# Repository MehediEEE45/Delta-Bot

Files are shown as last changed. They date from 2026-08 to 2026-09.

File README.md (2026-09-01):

# Delta-Bot

A small desk robot built on an ESP32-C3. It shows a face on a 128×64 OLED,
reacts when you tap it, drives around from a web page on your phone, and keeps
a to-do list and a Pomodoro timer that you can see without picking up anything.

I built it because I wanted something on my desk that felt like it was *there* —
not another blinking status LED. Most of the work went into the face.

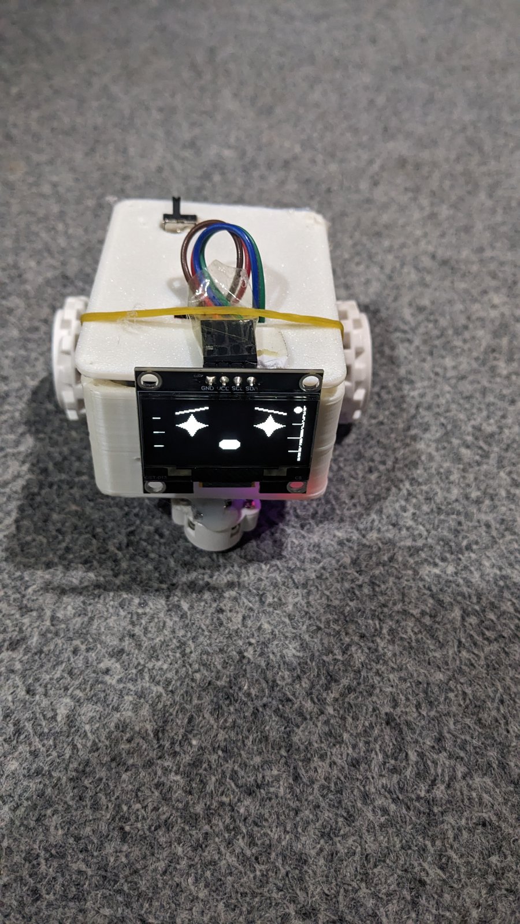
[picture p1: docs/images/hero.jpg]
Delta-Bot, face on






---

## What it does

| | |
| :--- | :--- |
| **Animated face** | The screen it boots to. Nine expressions on the OLED, each with its own eye shape, brow angle and mouth. Blinks at random intervals, drifts slightly when idle, and glances around on its own. Left alone it eases into a new expression every 15-30 seconds. |
| **Touch** | One capacitive pad, and the only control you need. A tap steps to the next screen, a triple tap steps back, a double tap throws a random expression on the face, and holding it puts the bot to sleep. |
| **RC driving** | A D-pad on the web page drives the two motors. The eyes lean into the turn. Motors cut out after one second if the browser stops sending, so a dropped connection can't run it off the desk. |
| **Voice** | The web page uses the browser's own speech recognition — say "forward", "left", "happy". No cloud service, no API key. Needs a secure page (see below); heard text is echoed to both the web page and the OLED. |
| **Clock and weather** | NTP time on a decorative ring that sweeps once a minute, timezone and 12h/24h format set from the web page and applied instantly. Current conditions from Open-Meteo, location also set from the web page, with drawn icons for sun, cloud, fog, rain, snow and storms. |
| **To-do list** | Up to five tasks, added from the web page, ticked off from either end. Survives a reboot. |
| **Pomodoro** | Focus length is set from the web page (1-180 minutes, default 25), with a fixed 5-minute break; a ring sweeps around the display as the interval burns down. Pauses and resumes properly. |
| **Virtual pet** | The pet screen shows a full animated face — happy when cared for, sad or angry if left hungry — plus a brief eating animation right after you feed it. Feed it from the web page, or double-tap the pad on the pet screen to pat it. |
| **Pixel canvas** | A 16×16 grid on your phone draws straight onto the OLED. |
| **Desk guard** | Arm it, and anyone who touches the bot gets a flashing alarm face and a wheel twitch. |
| **Night mode** | Switches to a moon-and-stars screen after 22:00 and puts your mode back at 06:00. |

On power-up it paints a name card - a Δ mark that rises, then **DELTA** assembling
under it - which also proves the panel and the I²C wiring before Wi-Fi is even
attempted, then settles on the animated face.

The pad walks a fixed ring of eight screens: **face, clock, weather, tasks,
pomodoro, pet, quotes, music**. The event-driven screens (notice, reminder, desk
guard, decision, night, RC) are left out of the ring on purpose, since landing on
one by accident would only show you a stale or empty panel; those still appear
when the web page or a trigger pushes them.

Everything is served from the bot itself. There's no app and nothing phones home;
the only outbound request is the weather fetch.

---

## Hardware

### Parts list

| Part | Qty | Notes |
| :--- | :---: | :--- |
| ESP32-C3 SuperMini | 1 | Any ESP32-C3 board works. Build targets `esp32-c3-devkitm-1`, which is the standard stand-in — PlatformIO has no SuperMini definition. |
| 128×64 OLED, I²C | 1 | SSD1306 or SSD1305, 0.96". Get the one with the header on the **long** edge if you're printing the lid. |
| TB6612FNG motor driver | 1 | **Not a DRV8833.** See the warning below. |
| N20 gear motors, 6 V | 2 | 100–200 RPM is about right. Faster than that and it skitters. |
| TTP223 touch module | 1 | The cheap 3-pin one. |
| LiPo 3.7 V, ~1000 mAh | 1 | Plus a TP4056 charger board — get the variant **with** DW01 protection. |
| Wheels, 34 mm | 2 | For a 3 mm D-shaft. |

> ### The motor driver is not interchangeable
>
> The firmware drives **one PWM pin plus two direction pins per channel**
> (`PWMA` / `AIN1` / `AIN2`, plus `STBY`). That's the TB6612FNG interface.
>
> A **DRV8833 will not work with this wiring.** It has no `PWMA`/`PWMB` pins at
> all — you PWM the direction pins directly — and its enable is `nSLEEP`, not
> `STBY`. Wire a DRV8833 to this pinout and the motors will only ever run flat
> out. If a DRV8833 is what you have, tie `GPIO 1` to `nSLEEP` and rework
> `MotorController::setMotor()` to PWM the direction pins instead.

### Pinout

| Signal | GPIO | Goes to |
| :--- | :---: | :--- |
| I²C SDA | 8 | OLED SDA |
| I²C SCL | 9 | OLED SCL |
| Touch | 4 | TTP223 SIG |
| Left PWM | 3 | TB6612 PWMA |
| Left dir 1 | 5 | TB6612 AIN1 |
| Left dir 2 | 6 | TB6612 AIN2 |
| Right PWM | 0 | TB6612 PWMB |
| Right dir 1 | 7 | TB6612 BIN1 |
| Right dir 2 | 10 | TB6612 BIN2 |
| Standby | 1 | TB6612 STBY |

All of these live in [`include/Config.h`](include/Config.h) — the C3's GPIO
matrix means you can move any of them without touching another file.

### Wiring

```text
                     ┌──────────────────┐
     USB 5V ────────▶│  TP4056 + DW01   │
                     │   charge board   │
                     └───┬──────────┬───┘
                    BAT+ │          │ OUT+
                  ┌──────┴────┐     │
                  │ LiPo 3.7V │     │  3.2 - 4.2 V rail
                  └───────────┘     │
                                    ├──────────────────┐
                                    ▼                  ▼
                        ┌───────────────────┐   ┌─────────────┐
                        │  TB6612FNG   VM   │   │  ESP32-C3   │
                        │              VCC ◀├───┤ 3V3     5V  │
                        │              GND  │   │             │
                        │                   │   │             │
                        │  PWMA ◀───────────┼───┤ GPIO 3      │
                        │  AIN1 ◀───────────┼───┤ GPIO 5      │
                        │  AIN2 ◀───────────┼───┤ GPIO 6      │
                        │  PWMB ◀───────────┼───┤ GPIO 0      │
                        │  BIN1 ◀───────────┼───┤ GPIO 7      │
                        │  BIN2 ◀───────────┼───┤ GPIO 10     │
                        │  STBY ◀───────────┼───┤ GPIO 1      │
                        │                   │   │             │
                        │  AO1 AO2 BO1 BO2  │   │ GPIO 8 ─────┼──▶ OLED SDA
                        └───┬───┬───┬───┬───┘   │ GPIO 9 ─────┼──▶ OLED SCL
                            │   │   │   │       │             │
                          ┌─┴───┴─┐┌┴───┴─┐     │ GPIO 4 ◀────┼─── TTP223 SIG
                          │ N20 L ││ N20 R│     └─────────────┘
                          └───────┘└──────┘
                                              OLED + TTP223 VCC ── 3V3
                                              everything GND ───── common
```

```mermaid
graph LR
    BAT["LiPo 3.7V<br/>+ TP4056"] -->|VM, motor rail| DRV["TB6612FNG"]
    BAT -->|regulated| MCU["ESP32-C3"]
    MCU -->|3V3 logic| DRV
    MCU -->|"I2C · GPIO 8/9"| OLED["128x64 OLED"]
    TOUCH["TTP223"] -->|"GPIO 4"| MCU
    DRV --> ML["Left N20"]
    DRV --> MR["Right N20"]
    MCU -.->|"Wi-Fi · web UI"| PHONE["Your phone"]
```

### Three things that will bite you

**Power the motors from the battery, not the 3V3 pin.** `VM` on the TB6612 goes
to the LiPo rail; `VCC` is the logic supply and goes to 3V3. Every ground must be
common. Two N20s stalling will pull well over an amp, which no dev-board
regulator will survive.

**Feeding the ESP32 is the part worth thinking about.** A 3.7 V cell is below
what most 5 V pins want and above what's safe to inject straight into 3V3 at full
charge (4.2 V). A small boost converter to 5 V is the boring, correct answer.
Going LiPo-direct into 3V3 works right up until it doesn't.

**GPIO 8 and 9 are strapping pins.** That's the Arduino I²C default and normally
fine, but on a SuperMini board GPIO 8 usually also drives the onboard LED and
GPIO 9 is the BOOT button. If the bot sometimes refuses to start, this is the
first place to look: check for pull-ups on SDA/SCL and keep the leads short.

---

## Photos

| | |
| :--- | :--- |
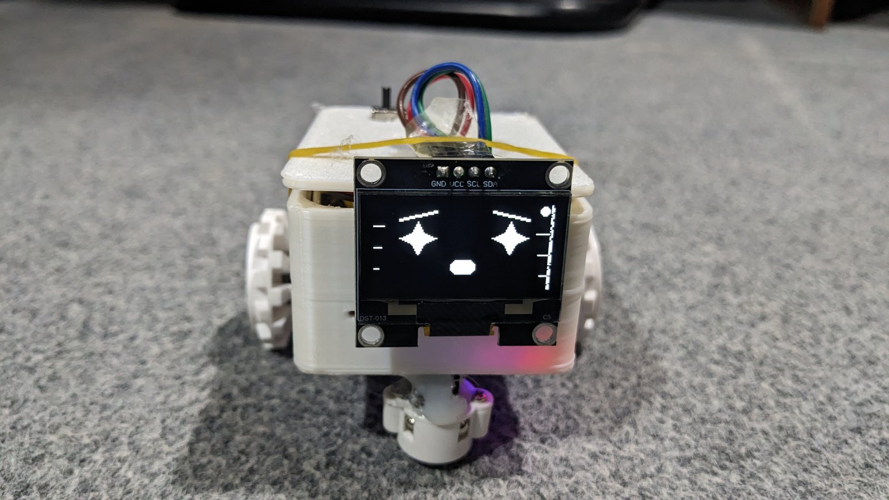
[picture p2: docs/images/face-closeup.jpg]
Face close-up
|  | **The face.** OLED filling the frame, shot slightly off-axis so the glass doesn't blow out. This is the project. |
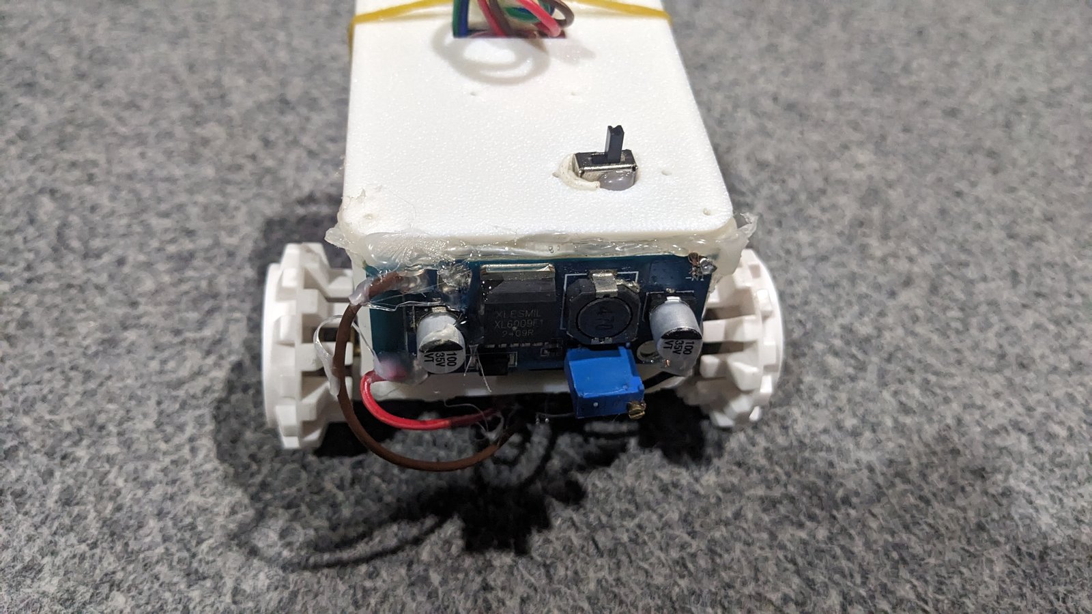
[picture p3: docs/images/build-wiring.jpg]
Bench wiring
|  | **The tail end.** Boost converter, power switch and the wiring that feeds the ESP32 — the single most useful photo in any hardware repo, since people copy wiring from photos, not diagrams. |
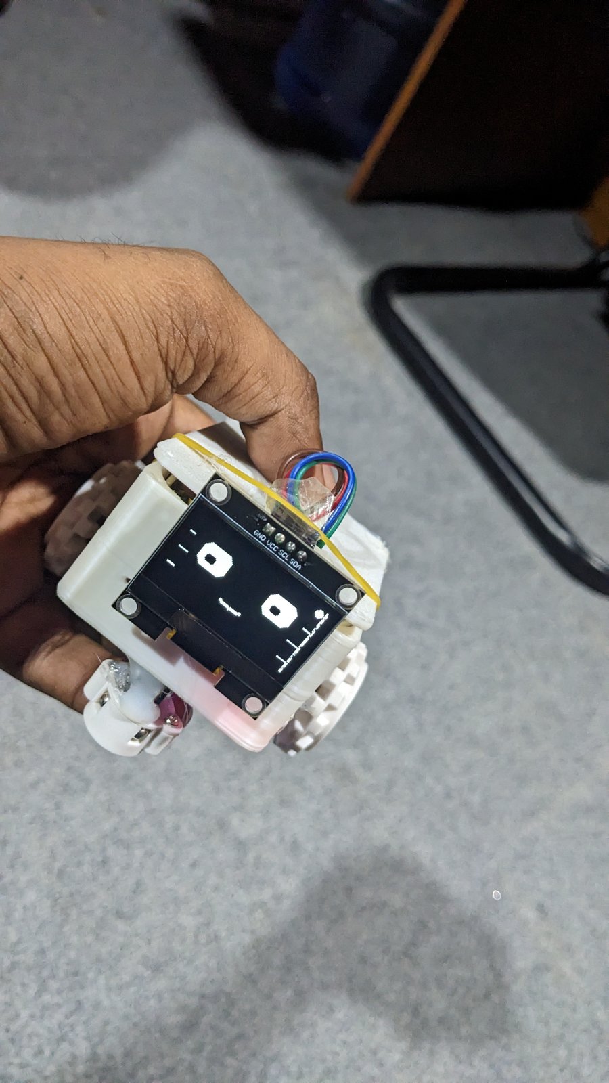
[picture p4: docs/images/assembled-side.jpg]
Held in hand, for scale
|  | **Actual size.** It's small — a hand around it answers "how big is it" faster than a ruler would. |

A phone screenshot of the web dashboard is still on the shot list — drop one
into `docs/images/web-ui.png` and add `![Web dashboard](docs/images/web-ui.png)`
here once it exists.

There's also a short clip of it driving around. GitHub won't play an `.mp4`
referenced by a repo-relative path inline, so once it's uploaded somewhere
(YouTube, etc.), add a link here:

<!-- **[Watch it drive](PASTE_VIDEO_URL_HERE)** -->

---

## Printed parts

Four parts in [`hardware/3d_models/`](hardware/3d_models): body, lid, a motor
bracket (print two), and a clamp that holds the touch sensor against the lid.
PLA, 0.2 mm, 20% infill, supports only on the body.

Print settings, tolerances and the assembly order are in
[`hardware/3d_models/README.md`](hardware/3d_models/README.md). The short version:
mount the motors before anything else goes in, or you won't reach the screws.

---

## Getting it running

You'll need [VS Code](https://code.visualstudio.com/) and the
[PlatformIO extension](https://platformio.org/platformio-ide).

```bash
git clone https://github.com/MehediEEE45/Delta-Bot.git
cd Delta-Bot
cp include/Secrets.h.example include/Secrets.h
```

Then fill in `include/Secrets.h`. It's gitignored, so nothing here gets committed:

```cpp
namespace Config {
constexpr char WIFI_SSID[]     = "YOUR_WIFI_SSID";
constexpr char WIFI_PASSWORD[] = "YOUR_WIFI_PASSWORD";

// Password for the fallback access point the bot starts when it can't
// join your network. Needs 8+ characters or it falls back to an open AP.
constexpr char FALLBACK_AP_PASSWORD[] = "CHANGE_ME_AP";

// Login for the web dashboard. Every endpoint that changes something is
// behind this. Leave the password empty to turn auth off — but then anyone
// on your network can drive the motors and rewrite your Wi-Fi settings.
constexpr char WEB_USER[]     = "delta";
constexpr char WEB_PASSWORD[] = "CHANGE_ME_WEB";
}
```

Plug the board in, hit Upload, then open the serial monitor at 115200 to find
the IP address. Open that in a browser and you're in.

If it can't reach your network it starts its own, called **Delta**. Join that and
go to `192.168.4.1` to set the real credentials.

---

## The console

The same command set is reachable three ways — over USB serial, over Bluetooth,
and from the web page's buttons. They all run through one parser, so a command
means the same thing wherever you type it.

**Over serial:** open the monitor at 115200 and type. `help` lists everything.

**Over Bluetooth:** the bot advertises as **DELTA** over BLE, exposing a Nordic
UART service. Any generic BLE terminal works — *Serial Bluetooth Terminal* in
BLE mode, or nRF Connect. There's no app to install.

> The ESP32-C3 has no classic Bluetooth, only BLE. A classic SPP pairing — the
> kind most "Bluetooth serial" tutorials describe — cannot work on this chip.

```
status              current mode, radio, battery, uptime
wifidiag (or wifi)  re-run the radio check and report
<mode>              face, clock, weather, tasks, pomodoro, pet, quotes, music...
<emotion>           happy, love, angry, cool, excited, sad, surprised, sleep, idle
drive <dir> [speed] forward | backward | left | right | stop, 0-255
restart (or reboot) reboot the board
help (or ?)         the list
```

### When Wi-Fi doesn't come up

`wifidiag` exists to answer one question: *is the radio broken, or is it
something ordinary?* It runs a live check and separates the cases:

| Reported | What it means |
| :--- | :--- |
| `radio-dead` | The MAC came back all-zero or all-`FF`. The PHY never started — this is the hardware. |
| `scan-empty` | Radio reports a real MAC but sees zero networks. Usually the antenna, not the chip. |
| `ssid-not-found` | Radio is fine, other networks are visible, yours isn't. Out of range or hidden. |
| `auth-failed` | Your network was seen and refused the association. Check the password. |
| `timeout` | Seen, but never answered. Weak signal or a busy AP. |

The check also runs at boot. If it fails, the reason goes on the OLED for a few
seconds before the setup card appears, so you can diagnose it without a laptop
attached. The same result is on the web dashboard under **Wi-Fi Diagnostics**.

---

## The web dashboard

Served straight off the board — one page, no build step, no dependencies.

- Drive pad with a speed slider
- Every emotion and mode as a button
- Task list with add, tick and delete
- Pomodoro (with a configurable focus length), reminders, notices, the 8-ball, the pet
- Pixel canvas that draws on the OLED as you tap
- Wi-Fi setup
- Clock & Region: timezone, 12h/24h format, and weather location — all applied
  immediately, no reboot
- Voice command, echoed to both the page and the OLED

Status polls every two seconds. If a request fails, the page tells you what
happened instead of silently doing nothing.

**Voice needs a secure page.** Browsers only allow microphone access on HTTPS
or `localhost` — a device on your LAN serving plain HTTP is blocked by the
browser before the bot ever sees a request. Standing up real HTTPS on a C3
just for this isn't worth it, so the practical fix is a browser flag: open
`chrome://flags/#unsafely-treat-insecure-origin-as-secure`, add
`http://<the-bot's-ip>`, enable it, and relaunch. That's a one-time setup per
browser/device, not a bot-side limitation you'll hit again.

---

## How the code is laid out

```
src/
  main.cpp           Wi-Fi bring-up, the loop
  AppController      Mode and emotion state machine
  FaceAnimator       Expression morphing, blinking, gaze — no display calls
  FaceRenderer       Everything that draws to the OLED
  TaskManager        Tasks, pet, pomodoro, reminders, canvas
  MotorController    TB6612 driver, watchdog, non-blocking wiggle
  CommandProcessor   One command parser, shared by every control surface
  SerialConsole      Line reader on USB serial
  BleConsole         Same console over a BLE UART service
  WiFiDiagnostics    Radio check that separates hardware from config faults
  WebController      HTTP server and the dashboard page
  Weather            Open-Meteo fetch, on its own FreeRTOS task
```

Four decisions worth explaining.

**The weather fetch runs on its own task.** A TLS handshake on a C3 takes a few
seconds, and doing that inside `loop()` froze the display and the web server
solid. The C3 is single-core, so the worker and the main loop take turns rather
than running in parallel, but the face keeps animating through it.

**`FaceAnimator` never touches the display.** It works out where everything
should be and hands over a struct; `FaceRenderer` draws it. That split means the
animation maths can be tested on a laptop with fake timestamps, and it keeps the
drawing code from accumulating state.

**One command parser, three front ends.** `CommandProcessor::execute()` writes
its output to an Arduino `Print&` rather than to `Serial` directly. That one
choice is what lets serial, BLE and the web API share a single parser — each
passes its own sink, and none of them can drift into meaning something different.

**BLE callbacks don't touch app state.** NimBLE runs its write callback on the
BLE stack's own task. Mutating `AppController` from there would race the main
loop, so the callback only posts the line to a queue and `loop()` drains it —
every command still executes from exactly one thread.

There's a preview script at [`tools/preview_face.py`](tools/preview_face.py) that
renders the expressions as ASCII, so you can check the geometry without flashing
anything. It caught three real layout bugs before they ever hit hardware.

---

## Rough edges

Things I know about, listed here rather than discovered by you:

- Tasks are capped at five. It's a fixed array.
- No OTA, so updates mean plugging in a cable. The build now uses the `huge_app`
  partition layout to fit the BLE stack, and that layout has no second OTA slot —
  so this is a deliberate trade rather than a space problem now.
- The battery gauge is wired in software but there's no divider on the board, so
  the API honestly reports `batteryMeasured: false` instead of inventing a number.
- No tests and no CI. Next on the list — the touch gesture logic and the Pomodoro
  maths are both pure functions and should be tested on a laptop.
- The face was tuned against an ASCII preview, not a real panel. Some of the
  geometry will want nudging once I've stared at it for a week.

---

## License

MIT. Do what you like with it.

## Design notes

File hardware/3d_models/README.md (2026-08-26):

# Printed parts

Four parts, all printable on a stock FDM machine with no exotic settings. I
print them in PLA; PETG is worth it for the body if the bot lives somewhere warm,
since a car dashboard will soften PLA.

## The parts

| File | What it is | Size (mm) | Triangles |
| :--- | :--- | :--- | ---: |
| `body.stl` | Main shell. Holds the battery, both motors, the driver board and the ESP32. | 54 × 72 × 32 | 3,616 |
| `lid.stl` | Top plate. The OLED sits in the window, touch pad underneath. | 54 × 72 × 2 | 1,792 |
| `n20_bracket.stl` | Motor mount. Print two. | 17.3 × 26.5 × 11.5 | 1,204 |
| `sensor_clamp.stl` | Retainer that holds the TTP223 board flat against the lid. | 20 × 10 × 3.4 | 828 |

Wheels aren't here. I used off-the-shelf 34 mm rubber wheels that push onto the
N20 D-shaft, which cost about a dollar a pair and grip far better than anything
I printed. If you want to print your own, the shaft is a 3 mm D with a 0.5 mm flat.

## Print settings

Nothing here is fussy. What I use:

- **Layer height** 0.2 mm. Drop to 0.16 mm if you want a cleaner OLED bezel.
- **Walls** 3 perimeters. The motor bracket takes real load, so don't go below this.
- **Infill** 20% gyroid.
- **Supports** only on `body.stl`, touching build plate. The other three print flat.
- **PLA** 205 °C nozzle, 60 °C bed.

The lid is 2 mm thick and prints in about fifteen minutes. Print a spare — it's
the part you'll re-cut if you move the display.

## Assembly order

Order matters here, because the body gets crowded fast.

1. Press the N20 motors into the two brackets, then screw the brackets into the
   floor of `body.stl`. Do this first: once the battery is in, you can't reach
   the screws.
2. Route the motor leads up the inside wall before anything else goes in.
3. Drop in the LiPo, then the TB6612 board, then the ESP32 last — it's the one
   you'll be unplugging most often.
4. Seat the OLED in the lid window from underneath. It's a friction fit; if it's
   loose, a strip of tape on the long edge takes up the slack.
5. Put the TTP223 face-down on the lid's inner boss and hold it with
   `sensor_clamp.stl`. It reads capacitively through 2 mm of PLA — it does not
   need a hole.
6. Push the wheels onto the D-shafts.

## Fit notes

These are the tolerances I printed against. If your printer runs tight, scale
the body 100.5% rather than reprinting everything.

- Motor bracket bore is sized for a standard 12 mm N20 barrel.
- The OLED window assumes the common 27 × 27 mm 4-pin I²C module. The 0.96"
  boards with the pin header on the long edge fit; the ones with it on the short
  edge do not.
- There's no strain relief on the USB port. Be gentle with it, or add a dab of
  hot glue once you've finished flashing.

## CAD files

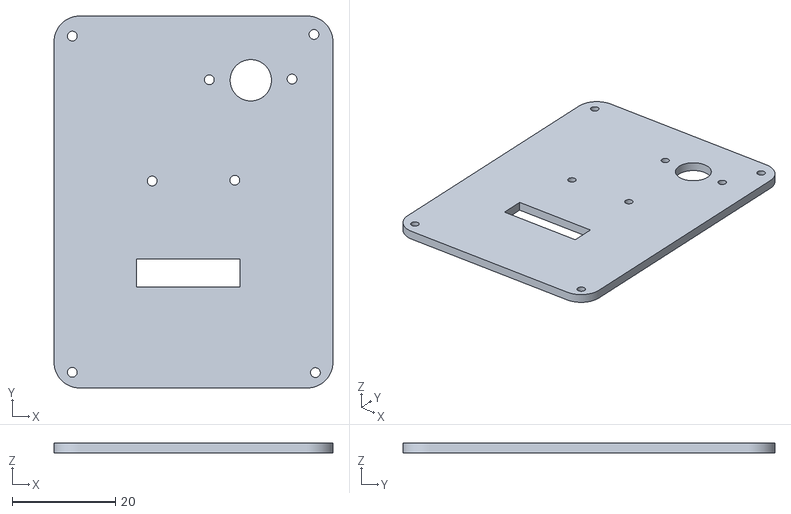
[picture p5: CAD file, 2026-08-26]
3d design/lid.stl
54.0 x 72.0 x 2.00

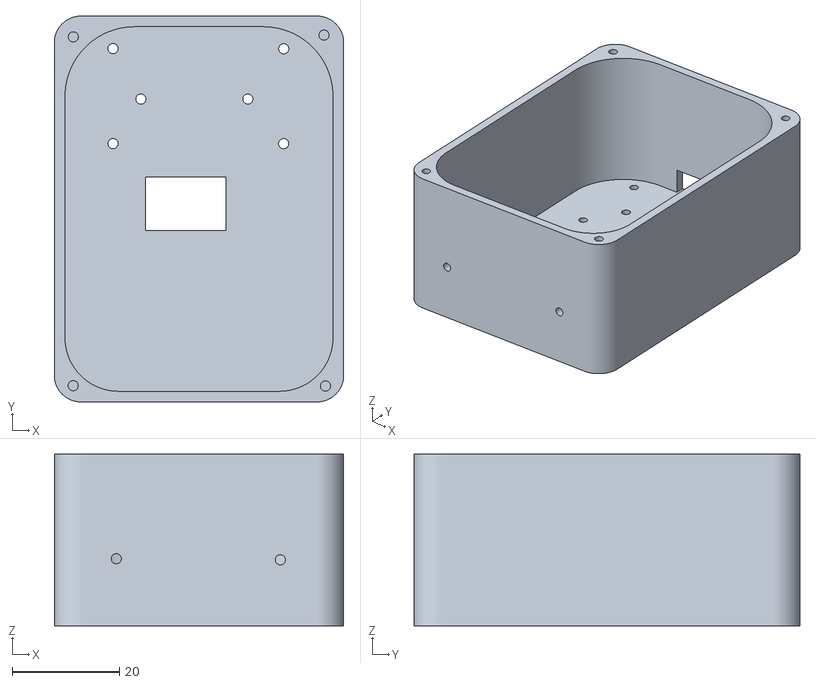
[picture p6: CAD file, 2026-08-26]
3d design/body.stl
54.0 x 72.0 x 32.0

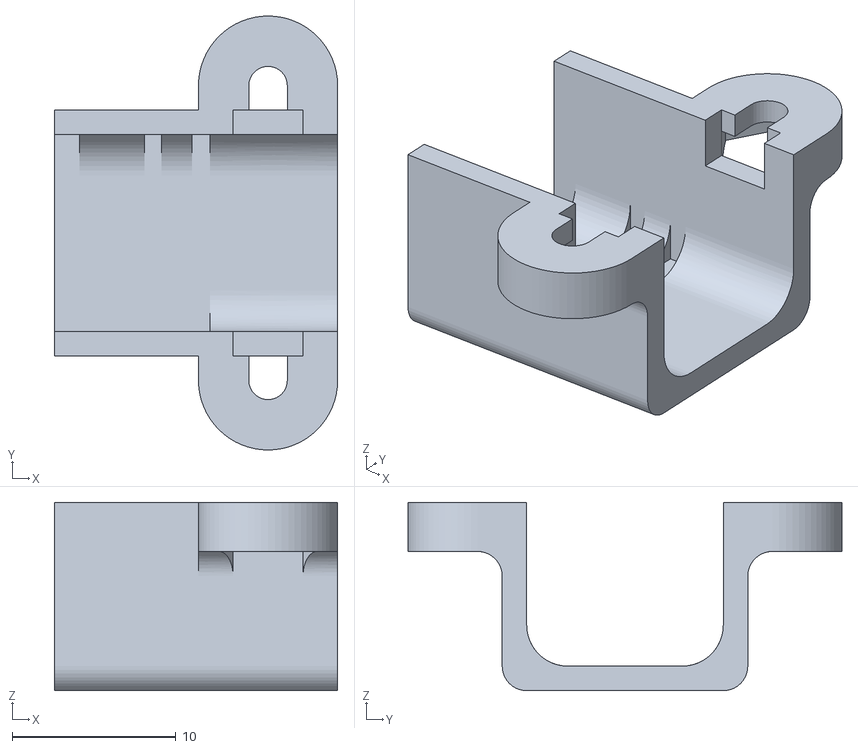
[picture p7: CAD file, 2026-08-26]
3d design/n20_bracket.stl
17.3 x 26.5 x 11.5

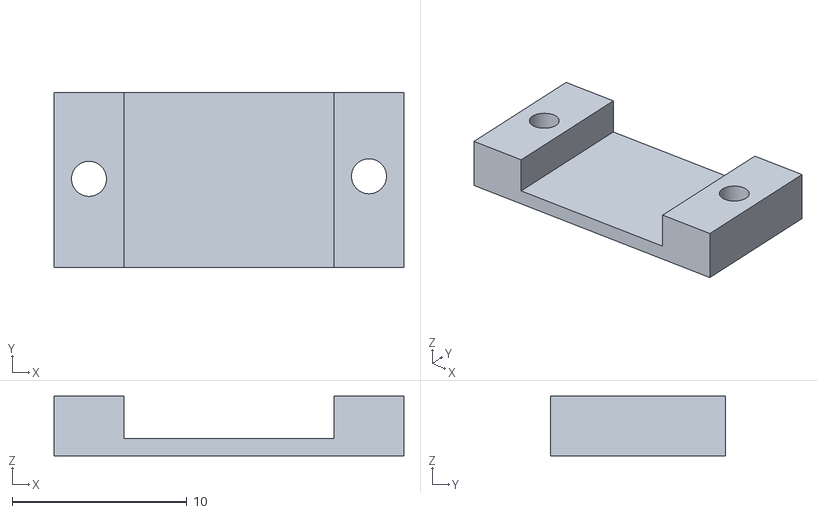
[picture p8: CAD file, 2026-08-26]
3d design/sensor_clamp.stl
20.0 x 10.00 x 3.40

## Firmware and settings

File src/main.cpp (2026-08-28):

#include <Arduino.h>
#include <WiFi.h>
#include "AppController.h"
#include "BleConsole.h"
#include "CommandProcessor.h"
#include "Config.h"
#include "FaceRenderer.h"
#include "SerialConsole.h"
#include "TouchSensor.h"
#include "WebController.h"
#include "Weather.h"
#include "WiFiDiagnostics.h"
#include "MotorController.h"

FaceRenderer renderer;
WeatherService weather;
TouchSensor touch(Config::TOUCH_PIN);
AppController app(renderer, weather);
MotorController motors(Config::MOTOR_LEFT_PWM, Config::MOTOR_LEFT_IN1, Config::MOTOR_LEFT_IN2, Config::MOTOR_RIGHT_PWM, Config::MOTOR_RIGHT_IN1, Config::MOTOR_RIGHT_IN2, Config::MOTOR_STBY);
CommandProcessor commands(app, motors);
WebController web(app, motors, commands);
SerialConsole serialConsole(commands);
BleConsole bleConsole(commands);

// What the OLED should tell the user once the radio has settled. Filled in by
// the bring-up path so the panel can repeat what used to be serial-only.
struct NetworkInfo {
  bool valid = false;
  bool apMode = false;
  String ssid;
  String password; // AP mode only; empty means the AP came up open
  String ip;
};

bool startFallbackAccessPoint(NetworkInfo& info) {
  WiFi.disconnect(true, true);
  delay(100);
  WiFi.mode(WIFI_AP);
  IPAddress apIp(192, 168, 4, 1);
  IPAddress apGateway(192, 168, 4, 1);
  IPAddress apSubnet(255, 255, 255, 0);
  WiFi.softAPConfig(apIp, apGateway, apSubnet);

  info.apMode = true;
  info.ssid = Config::FALLBACK_AP_SSID;

  if (WiFi.softAP(Config::FALLBACK_AP_SSID, Config::FALLBACK_AP_PASSWORD)) {
    Serial.print("Fallback website: http://");
    Serial.println(WiFi.softAPIP());
    Serial.print("Connect to Wi-Fi network: ");
    Serial.println(Config::FALLBACK_AP_SSID);
    Serial.println("Fallback password: (see include/Secrets.h)");
    info.valid = true;
    info.password = Config::FALLBACK_AP_PASSWORD;
    info.ip = WiFi.softAPIP().toString();
    web.begin();
    return true;
  }

  Serial.println("Secured fallback AP failed; retrying as open network.");
  if (WiFi.softAP(Config::FALLBACK_AP_SSID)) {
    Serial.print("Open fallback website: http://");
    Serial.println(WiFi.softAPIP());
    Serial.print("Connect to open Wi-Fi network: ");
    Serial.println(Config::FALLBACK_AP_SSID);
    info.valid = true;
    info.password = "";
    info.ip = WiFi.softAPIP().toString();
    web.begin();
    return true;
  }

  Serial.println("Fallback network failed to start.");
  return false;
}

// runWiFiDiagnostics() takes a plain function pointer, so the display it needs
// to keep alive is reached through the file-scope renderer rather than a
// capture.
void paintBootProgress(const char* headline, const char* detail) {
  renderer.showBootStatus(headline, detail, millis());
}

void connectWiFi(NetworkInfo& info) {
  String ssid = app.wifiSsid();
  String password = app.wifiPassword();
  ssid.trim();
  password.trim();

  if (ssid.isEmpty() || ssid == "YOUR_WIFI_SSID") {
    Serial.println("Wi-Fi not configured; starting fallback network.");
    renderer.showBootStatus("no wi-fi set", "starting setup ap", millis());
    startFallbackAccessPoint(info);
    return;
  }

  WiFi.setAutoReconnect(true);
  WiFi.disconnect(true, true);
  delay(150);

  const WiFiDiagnostics diag = runWiFiDiagnostics(ssid, password, 20000, paintBootProgress);
  commands.setLastDiagnostics(diag);
  Serial.println();
  diag.report(Serial);

  if (diag.fault == WiFiFault::None) {
    configTzTime(app.timezone(), "pool.ntp.org", "time.nist.gov");
    Serial.print("Delta web server: http://");
    Serial.println(WiFi.localIP());
    info.valid = true;
    info.apMode = false;
    info.ssid = ssid;
    info.ip = WiFi.localIP().toString();
    web.begin();
    return;
  }

  // Hold the reason on the panel before the setup card replaces it, so a
  // failure is readable without a laptop attached.
  if (renderer.ready()) {
    renderer.showWiFiDiagScreen(diag);
    delay(Config::WIFI_DIAG_CARD_MS);
  }
  Serial.println("Wi-Fi connection failed; starting Delta fallback network.");
  startFallbackAccessPoint(info);
}

// Plays the boot name card through to its settled frame. setup() has nothing
// else to do while it runs, so this blocks rather than threading splash state
// through loop().
void playSplash() {
  const unsigned long startedAt = millis();
  for (;;) {
    const unsigned long elapsed = millis() - startedAt;
    renderer.showSplash(elapsed);
    if (elapsed >= Config::SPLASH_HOLD_MS) return;
    delay(Config::SPLASH_FRAME_MS);
  }
}

// Leaves the SSID, password and address on screen long enough to be typed into
// a phone. The web server is already listening by this point, so keep pumping
// it instead of blocking on a bare delay.
void holdNetworkCard(const NetworkInfo& info) {
  if (!info.valid || !renderer.ready()) return;
  renderer.showNetworkCard(info.apMode, info.ssid, info.password, info.ip);
  const unsigned long startedAt = millis();
  while (millis() - startedAt < Config::NETWORK_CARD_MS) {
    web.update();
    delay(10);
  }
}

void setup() {
  Serial.begin(115200);
  delay(500);
  Serial.println("Delta booting");
  if (!renderer.begin()) {
    Serial.println("Continuing headless; the web UI still works.");
  } else {
    // Name card first, so a bare panel proves itself before Wi-Fi is tried.
    playSplash();
  }
  touch.begin();
  weather.begin();
  motors.begin();
  app.begin();
  NetworkInfo network;
  connectWiFi(network);
  holdNetworkCard(network);
  // BLE comes up after Wi-Fi so the radio is not being shared during the
  // association attempt the diagnostics depend on.
  bleConsole.begin();
  serialConsole.begin();
}

void loop() {
  web.update();
  const unsigned long now = millis();
  serialConsole.update();
  bleConsole.update();
  const TouchEvent touchEvent = touch.update(now);
  app.handleTouch(touchEvent, now);
  // Desk Guard warning pulse: a caught intruder gets a wheel wiggle. main owns
  // both objects, so the alarm stays decoupled from the motor driver.
  if (app.taskManager().consumeGuardAlarmPulse()) {
    motors.startShake(now);
  }
  web.update();
  motors.update(now);
  app.update(now);
}

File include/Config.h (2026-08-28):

#pragma once

#include <Arduino.h>
#include "Secrets.h"

namespace Config {
// 400kHz costs ~23ms for a full 1KB frame, which caps the face near 20fps.
// Most SSD130x modules run happily at 1000000; raise this and re-test if the
// animation looks choppy. Depends on your pull-ups and lead length.
constexpr uint32_t I2C_CLOCK_HZ = 400000;

constexpr uint8_t I2C_SDA_PIN = 8;
constexpr uint8_t I2C_SCL_PIN = 9;
constexpr uint8_t TOUCH_PIN = 4;
constexpr uint8_t MOTOR_LEFT_PWM = 3;
constexpr uint8_t MOTOR_LEFT_IN1 = 5;
constexpr uint8_t MOTOR_LEFT_IN2 = 6;
constexpr uint8_t MOTOR_RIGHT_PWM = 0;
constexpr uint8_t MOTOR_RIGHT_IN1 = 7;
constexpr uint8_t MOTOR_RIGHT_IN2 = 10;
constexpr uint8_t MOTOR_STBY = 1;
constexpr bool TOUCH_ACTIVE_HIGH = true;
constexpr uint8_t OLED_ADDRESS = 0x3C;
constexpr uint8_t BATTERY_ADC_PIN = 255;
constexpr float BATTERY_DIVIDER_RATIO = 2.0f;
constexpr float BATTERY_EMPTY_VOLTAGE = 3.30f;
constexpr float BATTERY_FULL_VOLTAGE = 4.20f;
constexpr char DEVICE_NAME[] = "DELTA";
constexpr char FALLBACK_AP_SSID[] = "Delta";
// Bangladesh Standard Time, UTC+6, no DST. POSIX TZ offsets are west-positive,
// so the fixed 6-hour advance is written as -6.
constexpr char TIMEZONE[] = "BST-6";

// Dhaka. Both the timezone and this default only matter until the web
// dashboard's Clock & Region panel saves a real location; from then on
// DeviceSettings' persisted value wins.
constexpr char WEATHER_LATITUDE[] = "23.8103";
constexpr char WEATHER_LONGITUDE[] = "90.4125";

constexpr unsigned long TOUCH_DEBOUNCE_MS = 50;
constexpr unsigned long GESTURE_WINDOW_MS = 250;
constexpr unsigned long LONG_PRESS_MS = 1500;
constexpr unsigned long WEATHER_REFRESH_MS = 900000;
constexpr unsigned long WEATHER_RETRY_MS = 60000;
constexpr unsigned long WEATHER_HTTP_TIMEOUT_MS = 8000;
constexpr unsigned long WEATHER_TLS_HANDSHAKE_TIMEOUT_S = 10;
constexpr unsigned long IDLE_SLEEP_MS = 600000;
constexpr unsigned long IDLE_SURPRISE_INTERVAL_MS = 30000;
constexpr unsigned long IDLE_SURPRISE_DURATION_MS = 2000;
constexpr unsigned long STATUS_REFRESH_MS = 1000;

// Battery sampling: average this many reads, no more often than this interval.
constexpr uint8_t BATTERY_SAMPLE_COUNT = 8;
constexpr unsigned long BATTERY_SAMPLE_INTERVAL_MS = 5000;

// Pomodoro Timer Constants
constexpr unsigned long POMODORO_WORK_MS = 25 * 60 * 1000UL;
constexpr unsigned long POMODORO_BREAK_MS = 5 * 60 * 1000UL;

// Virtual Pet Constants
constexpr unsigned long PET_DECAY_INTERVAL_MS = 60000UL; // decay stats every minute

// NVS is only rewritten this often for background state (pet decay, battery),
// so idle decay cannot burn through the flash. Explicit user edits save at once.
constexpr unsigned long FLASH_THROTTLE_MS = 300000UL; // 5 minutes

// Night Mode Hours
constexpr int NIGHT_START_HOUR = 22; // 10 PM
constexpr int NIGHT_END_HOUR = 6;    // 6 AM

// Canvas Size
constexpr uint8_t CANVAS_WIDTH = 128;
constexpr uint8_t CANVAS_HEIGHT = 64;
constexpr uint8_t CANVAS_CELLS_X = 16;
constexpr uint8_t CANVAS_CELLS_Y = 16;
constexpr size_t CANVAS_CELL_COUNT = CANVAS_CELLS_X * CANVAS_CELLS_Y;
// Canvas buffer is stored in Adafruit_GFX drawBitmap layout: row-major,
// MSB-first, CANVAS_WIDTH/8 bytes per row.
constexpr size_t CANVAS_BUFFER_BYTES = (CANVAS_WIDTH / 8) * CANVAS_HEIGHT;

// Frame pacing. A full 1KB I2C transfer at 400kHz already costs ~25ms, so
// anything faster than this starves the web server and touch sampling.
constexpr unsigned long MUSIC_FRAME_MS = 50;
constexpr unsigned long CLOCK_FRAME_MS = 200;
// Face modes animate; info screens do not need the bandwidth.
constexpr unsigned long FACE_FRAME_MS = 45;

// Boot splash. The mark, then the name, then the tagline animate in over
// SPLASH_INTRO_MS, and the finished card sits still for the rest of
// SPLASH_HOLD_MS so "DELTA" is readable even when the rest of setup() is quick.
constexpr unsigned long SPLASH_INTRO_MS = 1600;
constexpr unsigned long SPLASH_HOLD_MS = 2400;
constexpr unsigned long SPLASH_FRAME_MS = 40;

// setup() blocks for a scan plus up to 20s of association, so the progress
// card repaints at this rate to prove the bot has not hung. A full frame is
// ~25ms of I2C at 400kHz; do not push this much below that.
constexpr unsigned long BOOT_STATUS_FRAME_MS = 120;

// How long the "here is how to reach me" card holds before the normal screens
// take over. Long enough to type an SSID and password into a phone.
constexpr unsigned long NETWORK_CARD_MS = 6000;

// How long a failed radio check stays on the panel before the setup card
// replaces it. Long enough to read the fault line and the MAC.
constexpr unsigned long WIFI_DIAG_CARD_MS = 4000;
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

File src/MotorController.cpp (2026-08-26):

#include "MotorController.h"
#include "Config.h"

MotorController::MotorController(uint8_t leftPwm, uint8_t leftIn1, uint8_t leftIn2, uint8_t rightPwm, uint8_t rightIn1, uint8_t rightIn2, uint8_t standby)
    : leftPwm_(leftPwm), leftIn1_(leftIn1), leftIn2_(leftIn2), rightPwm_(rightPwm), rightIn1_(rightIn1), rightIn2_(rightIn2), standby_(standby) {}

void MotorController::begin() {
    pinMode(leftPwm_, OUTPUT);
    pinMode(leftIn1_, OUTPUT);
    pinMode(leftIn2_, OUTPUT);
    pinMode(rightPwm_, OUTPUT);
    pinMode(rightIn1_, OUTPUT);
    pinMode(rightIn2_, OUTPUT);
    pinMode(standby_, OUTPUT);
    digitalWrite(standby_, HIGH);
    stop();
    lastCommandAt_ = millis();
}

void MotorController::setMotor(uint8_t pwm, uint8_t in1, uint8_t in2, int16_t value) {
    if (value > 0) {
        digitalWrite(in1, HIGH);
        digitalWrite(in2, LOW);
        analogWrite(pwm, value);
    } else if (value < 0) {
        digitalWrite(in1, LOW);
        digitalWrite(in2, HIGH);
        analogWrite(pwm, -value);
    } else {
        digitalWrite(in1, LOW);
        digitalWrite(in2, LOW);
        analogWrite(pwm, 0);
    }
}

void MotorController::applyCommand(MotorCommand command, uint8_t speed) {
    const int16_t s = static_cast<int16_t>(speed);
    switch (command) {
        case MotorCommand::Forward:
            setMotor(leftPwm_, leftIn1_, leftIn2_, s);
            setMotor(rightPwm_, rightIn1_, rightIn2_, s);
            break;
        case MotorCommand::Backward:
            setMotor(leftPwm_, leftIn1_, leftIn2_, -s);
            setMotor(rightPwm_, rightIn1_, rightIn2_, -s);
            break;
        case MotorCommand::Left:
            setMotor(leftPwm_, leftIn1_, leftIn2_, -s);
            setMotor(rightPwm_, rightIn1_, rightIn2_, s);
            break;
        case MotorCommand::Right:
            setMotor(leftPwm_, leftIn1_, leftIn2_, s);
            setMotor(rightPwm_, rightIn1_, rightIn2_, -s);
            break;
        default:
            setMotor(leftPwm_, leftIn1_, leftIn2_, 0);
            setMotor(rightPwm_, rightIn1_, rightIn2_, 0);
            break;
    }
}

void MotorController::drive(MotorCommand command, uint8_t speed) {
    shakeStep_ = 0; // an explicit drive command cancels a shake in progress
    command_ = command;
    speed_ = command == MotorCommand::Stop ? 0 : speed;
    lastCommandAt_ = millis();
    applyCommand(command_, speed_);
}

void MotorController::startShake(unsigned long now) {
    shakeStep_ = 1;
    shakeStepAt_ = now;
    command_ = MotorCommand::Left;
    speed_ = Config::MOTOR_SHAKE_SPEED;
    lastCommandAt_ = now;
    applyCommand(MotorCommand::Left, Config::MOTOR_SHAKE_SPEED);
}

bool MotorController::isShaking() const {
    return shakeStep_ != 0;
}

void MotorController::update(unsigned long now) {
    if (shakeStep_ != 0) {
        if (now - shakeStepAt_ < Config::MOTOR_SHAKE_LEG_MS) return;
        shakeStepAt_ = now;
        lastCommandAt_ = now;
        if (shakeStep_ == 1) {
            shakeStep_ = 2;
            command_ = MotorCommand::Right;
            applyCommand(MotorCommand::Right, Config::MOTOR_SHAKE_SPEED);
        } else {
            shakeStep_ = 0;
            stop();
        }
        return;
    }

    if (command_ != MotorCommand::Stop && now - lastCommandAt_ >= Config::MOTOR_WATCHDOG_MS) stop();
}

void MotorController::stop() {
    shakeStep_ = 0;
    command_ = MotorCommand::Stop;
    speed_ = 0;
    applyCommand(MotorCommand::Stop, 0);
}

const char* MotorController::commandName() const {
    switch (command_) {
        case MotorCommand::Forward: return "forward";
        case MotorCommand::Backward: return "backward";
        case MotorCommand::Left: return "left";
        case MotorCommand::Right: return "right";
        default: return "stop";
    }
}

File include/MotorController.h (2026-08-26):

#pragma once

#include <Arduino.h>

enum class MotorCommand {
    Stop,
    Forward,
    Backward,
    Left,
    Right
};

class MotorController {
public:
    MotorController(uint8_t leftPwm, uint8_t leftIn1, uint8_t leftIn2, uint8_t rightPwm, uint8_t rightIn1, uint8_t rightIn2, uint8_t standby);
    void begin();
    void drive(MotorCommand command, uint8_t speed);
    void stop();
    void update(unsigned long now);
    const char* commandName() const;

    // Starts a short left-right wiggle that runs from update(); never blocks.
    void startShake(unsigned long now);
    bool isShaking() const;

private:
    uint8_t leftPwm_;
    uint8_t leftIn1_;
    uint8_t leftIn2_;
    uint8_t rightPwm_;
    uint8_t rightIn1_;
    uint8_t rightIn2_;
    uint8_t standby_;
    MotorCommand command_ = MotorCommand::Stop;
    uint8_t speed_ = 0;
    unsigned long lastCommandAt_ = 0;

    uint8_t shakeStep_ = 0; // 0 = idle
    unsigned long shakeStepAt_ = 0;

    void setMotor(uint8_t pwm, uint8_t in1, uint8_t in2, int16_t value);
    void applyCommand(MotorCommand command, uint8_t speed);
};

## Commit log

2026-08-22 docs: add hero banner render, ASCII circuit diagram, and Mermaid architecture to README
2026-08-22 feat: add open-source 3D printable STL chassis models and 3D printing guide
    [delta_bot_chassis.stl, delta_bot_head_cover.stl, delta_bot_wheel_left.stl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]
2026-08-26 fix: night mode lockout, right motor PWM pin, and Wi-Fi placeholder
    checkNightMode() ran every loop pass and force-set mode_ = Night whenever
    the hour was outside 06:00-22:00, so every web command was reverted within
    milliseconds and the bot was unusable at night. It was also one-way: after
    06:00 the condition simply stopped firing, leaving the night screen up all
    day. It is now edge-triggered, records preNightMode_, and restores it on the
    morning edge. Choosing a mode overrides the latch until the next edge.
    MotorController::begin() never called pinMode() on rightPwm_. It survived
    only because the ESP32 analogWrite() shim auto-attaches an LEDC channel.
    The unconfigured-Wi-Fi guard compare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
    [MotorController.cpp, MotorController.h, main.cpp]
2026-08-26 fix: move weather fetch off the main loop onto a FreeRTOS task
    Three compounding problems meant weather essentially never worked:
    - http.setTimeout(1000) allowed one second for a TLS handshake plus GET to
    api.open-meteo.com. A TLS 1.2 handshake on a C3 alone typically takes
    1.5-4s, so the request timed out nearly every time.
    - The fetch ran synchronously inside loop(), freezing the display, the web
    server and the motor watchdog for its whole duration.
    - AppController only called weather_.update() while the weather screen was
    showing, so switching to it displayed "-- C" and then blocked. The README
    advertised background updates that did not exist.
    The fetch now runs on its own 8KB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
    [Weather.cpp]
2026-08-26 feat: authenticate the web API and validate every request
    The server had no authentication of any kind. Anyone on the LAN could drive
    the motors, rewrite the Wi-Fi credentials and reboot the board. The fallback
    AP password was also a hardcoded constant in a public repo.
    Every endpoint is now behind HTTP basic auth, and the AP password plus the
    web credentials moved into the gitignored Secrets.h. Setting WEB_PASSWORD to
    an empty string disables auth for anyone who wants the old behaviour.
    Request handling:
    - /api/canvas ignored the deserializeJson() result and cleared the canvas
    before validating, so a malformed POST silently wiped the drawing. It now
    validates the parse and the 256-cel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
2026-08-26 fix: stop burning NVS on pet decay, and persist all modes
    updatePet() called saveToFlash() on every decay tick: once a minute, forever,
    rewriting all five task strings and both pet stats whether or not anything a
    user cares about changed. That is ~1440 NVS commits a day just sitting idle,
    each one blocking the loop on a flash write.
    Background decay now sets a dirty flag and maybePersist() batches the commit
    to at most once per FLASH_THROTTLE_MS. Explicit user edits (add, toggle,
    delete, feed, pet) still save immediately.
    DeviceSettings mapped every mode that was not Music or Weather onto TimeDate,
    so 11 of the 14 modes could not be saved as the boot mode. It now stores the
    enum value dire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
    [TaskManager.h]
2026-08-26 fix: reset text size between screens and blit the canvas
    render() reset clearDisplay() and setTextColor() but not setTextSize(). Since
    the time, weather, pomodoro and guard screens leave the size at 2, the common
    Time -> Notice / Quotes / Pet / 8-Ball transition drew double-height text that
    overflowed off the panel.
    drawCanvasScreen() walked all 128x64 pixels with a bounds-checked drawPixel()
    five times a second. The buffer is now in GFX bitmap layout, so it is a single
    drawBitmap() instead of 8192 calls.
    Music mode ran at a 25ms frame time, but a full 1KB I2C transfer at 400kHz
    costs ~25ms on its own, so the loop was I2C-bound and the web server and touch
    sampling got whatever was left. 5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
    [FaceRenderer.cpp]
2026-08-26 build: pin SSD1305, enable warnings, correct the motor driver docs
    lib_deps tracked the default branch of Adafruit_SSD1305, so builds were not
    reproducible and an upstream change could break the firmware silently. Pinned
    to tag 2.2.3, which is what it already resolved to. Added -Wall -Wextra (the
    tree builds clean) and the exception decoder so panics give a file:line
    backtrace.
    The README pin table specified a DRV8833 with PWMA/PWMB pins. The DRV8833 has
    no such pins: PWM is applied directly to AIN1/AIN2 and its enable is nSLEEP,
    not STBY. The separate-PWM-plus-two-direction-pins topology the firmware
    drives is the TB6612FNG interface. Anyone wiring from that table with a real
    DRV8833 got m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
    [Config.h]
2026-08-26 build: check unused parameters in project sources only
    The ESP32 platform injects -Wno-unused-parameter into every compile, after
    our own flags, so -Wextra never reported it. That flag is exactly what hid
    drawSimpleRobotFace() accepting an `emotion` argument and never reading it -
    the reason all eight emotions currently render identically.
    build_unflags would strip it globally and bury us in framework warnings we
    cannot fix, so build_src_flags re-enables the check for project sources only.
    It surfaces 16 real cases, all in FaceRenderer.cpp; the next commit clears
    them.
2026-08-26 feat: weather icons, pomodoro ring, and a desk guard motor pulse
    Three README features that were advertised but never implemented, plus the
    warning cleanup the previous commit surfaced.
    Weather screen. It fetched `weather_code` from Open-Meteo, stored it, and
    never displayed it - weatherCodeText() and drawWeatherIcon() both had zero
    call sites, so the screen was a second clock plus a number. Now an icon set
    drawn as 1-bit glyphs: a sun with slowly rotating rays, a cloud built from
    three overlapping circles, rain as streaks falling on a loop, snow as
    drifting sparkles, and a lightning bolt for storms. Layout reworked to icon
    on the left, temperature at size 2, condition text beneath.
    Pomodo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
    [FaceRenderer.cpp, TaskManager.h, main.cpp]
2026-08-26 feat: animated face with per-emotion expressions, blinking and gaze
    Delivers the two TODO(phase-2) markers: drawSimpleRobotFace() and
    drawRCCarFace() both accepted an `emotion` argument and ignored it, so all
    eight emotions rendered as the same two rounded rectangles jittering 1px on a
    500ms square wave.
    Adds FaceAnimator, which holds every piece of animation state and no display
    reference at all. It emits a fully resolved FaceFrame per tick, so the drawing
    code stays stateless and the motion logic can be stepped with synthetic
    timestamps in a native test later.
    Expressions are a table, not a function per emotion. FaceParams is all floats
    - eye size, radius, gap, brow lift and angle, mouth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
    [Config.h, FaceAnimator.h]
2026-08-26 docs: publish the real STL models and rewrite the README
    The four files in hardware/3d_models/ were 179-byte stubs. Each contained a
    single flat triangle and nothing else, so anyone who followed the README and
    downloaded them got an empty model. The real parts were sitting untracked in
    "3d design/". Swapped them in after checking each one parses as a valid binary
    STL with sensible dimensions:
    body.stl 3616 tris 54 x 72 x 32 mm
    lid.stl 1792 tris 54 x 72 x 2 mm
    n20_bracket.stl 1204 tris 17.3 x 26.5 x 11.5 mm
    sensor_clamp.stl 828 tris 20 x 10 x 3.4 mm
    The lid footprint matches the body exactly, which is a good sign they belong to
    the same revision. Part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
    [body.stl, delta_bot_chassis.stl, delta_bot_head_cover.stl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]
2026-08-28 feat: complete feature set with clock settings, voice fixes, and pet animation
    Implements seven major features:
    - Clock & Region settings: configurable timezone, 12h/24h format, weather location (web UI, applied instantly, persisted)
    - Weather: location-aware fetch from Open-Meteo, fog code label fix
    - Voice: error handling for secure-context issues + Chrome-flag hint, single-shot motor fix for voice drive commands, recognized speech echoed to OLED notice screen
    - Pomodoro: configurable focus duration (1-180 min, default 25) set from web and persisted
    - Clock screen: ring dial redesign with live seconds indicator, time and date centered inside
    - Virtual pet: animated face reflecting mood (h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
    [body.stl, lid.stl, n20_bracket.stl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]
2026-09-01 docs: swap concept render for real build photos
    Replace the placeholder hero render and the photo shot-list with actual
    shots of the finished bot. Raw camera originals and the demo video stay
    local in docs/images/raw/ (gitignored) instead of bloating the repo.
